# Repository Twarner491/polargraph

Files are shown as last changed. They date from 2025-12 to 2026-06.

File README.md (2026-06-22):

# Polargraph

*Have a hard time deciding what to hang on your walls? Boy, do I have the solution for you.*

Wall mounted, web accessible polargraph pen plotter. Full project writeup at [teddywarner.org/Projects/Polargraph](https://teddywarner.org/Projects/Polargraph/).

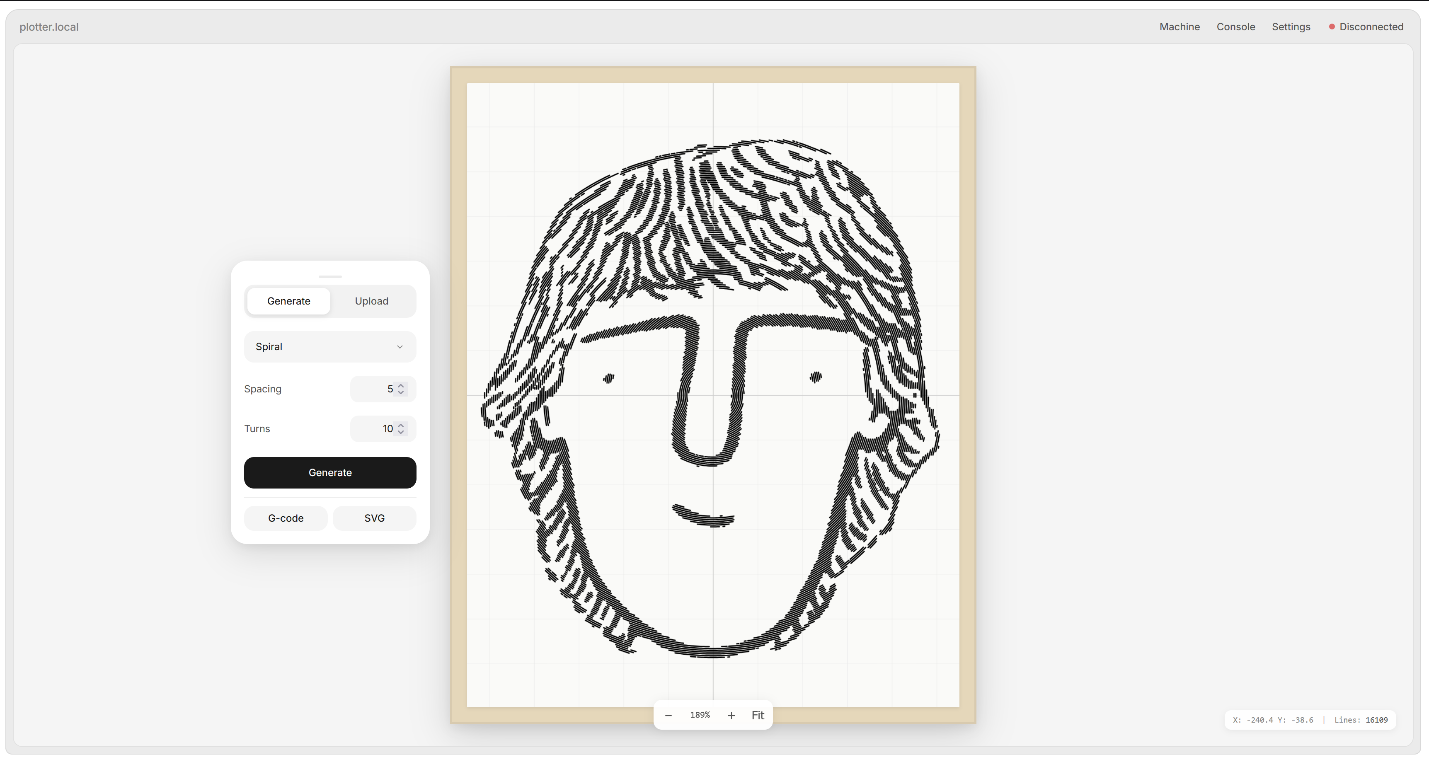
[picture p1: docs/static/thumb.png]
polargraph


---

All project CAD may be found in the [hardware](https://github.com/Twarner491/polargraph/tree/main/hardware) directory in this repo. Full assembly instructions may be found in the [full project writeup](https://teddywarner.org/Projects/Polargraph/).

### BOM

| Qty | Description | Price | Link | Notes |
|-----|---|---|---|---|
| 1 | Raspberry Pi 5 | $89.94 | [Link](https://amzn.to/4vjlhqI) | 8GB |
| 1 | Raspberry Pi 5 Active Cooler | $9.90 | [Link](https://amzn.to/4va5XNp) | |
| 1 | Micro SD Card | $16.68 | [Link](https://amzn.to/3SCuewS) | ≥32GB |
| 1 | RAMPS 1.4 Shield | $9.39 | [Link](https://amzn.to/4uwKVak) | |
| 2 | A4988 Stepper Drivers | $9.98 | [Link](https://amzn.to/4uupO8D) | |
| 2 | Nema 17 Pancake Stepper | $21.00 | [Link](https://amzn.to/3QmylfZ) | 42mm x 23mm |
| 1 | MG90S Micro Servo | $9.99 | [Link](https://amzn.to/3QA8Mbn) | 9G |
| 2 | Stepper Motor Cables | $10.99 | [Link](https://amzn.to/4xJbtZ5) | 2M length |
| 2 | GT2 Timing Belt | $19.98 | [Link](https://amzn.to/4vKBLYQ) | 6mm width, 5M length |
| 2 | GT2 Timing Belt Pulley | $6.99 | [Link](https://amzn.to/4opOSfu) | 16 Teeth, 5mm bore |
| 2 | 6806-2RS Ball Bearings | $30.00 | [Link](https://amzn.to/4v6W5ng) | 30mm x 42mm x 7mm |
| 1 | 12V Power Supply | $35.00 | [Link](https://amzn.to/4eqKFUB) | |
| 1 | DC/DC Buck Boost | $9.99 | [Link](https://amzn.to/4xqg8i5) | |
| 1 | C14 AC Inlet | $9.04 | [Link](https://amzn.to/4ahK7z9) | |
| 1 | AC Power Cord | $9.39 | [Link](https://amzn.to/4fIMUF0) | Down angle |
| - | 14 Gauge Wire | $13.99 | [Link](https://a.co/d/foroDOo) | A couple feet |
| 2 | Limit Switch | $5.99 | [Link](https://amzn.to/3S1PjRm) | |
| 3 | Tungsten Weights | $89.97 | [Link](https://amzn.to/4oAiBTd) | |
| 1 | 1/4" Maple Plywood | $37.71 | [Link](https://www.lowes.com/pd/Top-Choice-SkyPly-1-4-in-HPVA-Maple-Plywood-Application-as-4-x-8/1000083311) | 4'x8' sheet |
| 4 | 1"x3" Spruce Pine Boards | $27.92 | [Link](https://www.lowes.com/pd/1-in-x-3-in-x-8-ft-Spruce-Pine-Fir-Furring-Strip/5014776481) | 8' length |
| 1 | Wood PLA | $25.99 | [Link](https://amzn.to/4uAzpLj) | 1.75mm, 1 spool |
| 1 | A0 Paper Roll | $29.86 | [Link](https://amzn.to/4uwP6Tw) | 36" x 1200" |
| 1 | SAKURA Pigma Micron 05 Pens | $20.97 | [Link](https://amzn.to/4fHYW1p) | Multicolor pack |
| 1 | French Cleat | $31.00 | [Link](https://www.homedepot.com/p/OOK-30-in-300-lbs-Picture-and-Mirror-French-Cleat-Hanging-System-534269/302022526) | 30 in. 300 lbs. |
| 1 | Felt Pads | $9.97 | [Link](https://www.homedepot.com/p/Everbilt-Assorted-Beige-Self-Adhesive-Round-Furniture-Sliders-Furniture-Pads-for-Hard-Floors-Surface-Bumpers-Value-Pack-108-Pc-49032/2068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) | Assorted Pack |
| - | M2 and M3 Hardware | - | - | Misc nuts and bolts |
| - | Jumper Wires | - | - | Misc |

*Total: ~$595.82*

### Kits

I offer a kit for the polargraph with electronics and neccessary hardware. I put up a store for some of my open-source projects and will soon be able to offer kits cheaper than buying all the components individually, once I start buying in bulk. Check it out!

- [GPENT kit](https://theodore.net/store/polargraph/)

---

**Raspberry Pi Setup**

Flash Raspberry Pi OS Lite (64-bit) and configure WiFi. SSH in:

```bash
ssh pi@raspberrypi.local
sudo apt update && sudo apt upgrade -y
```

Set hostname to `plotter`:

```bash
sudo hostnamectl set-hostname plotter
sudo nano /etc/hosts  # Change 127.0.1.1 to plotter
sudo reboot
```

Install dependencies:

```bash
sudo apt install -y python3-pip python3-venv avahi-daemon git
sudo systemctl enable avahi-daemon
```

**Clone Repository**

```bash
git clone https://github.com/Twarner491/polargraph.git ~/polargraph
cd ~/polargraph
python3 -m venv venv
source venv/bin/activate
pip install -r requirements.txt
```

**USB Permissions**

Set permissions for the plotter's USB serial connection:

```bash
sudo cp system-config/99-polargraph.rules /etc/udev/rules.d/
sudo udevadm control --reload-rules && sudo udevadm trigger
sudo usermod -a -G dialout pi
```

**Start Flask Server**

Enable the service to auto-start on boot. If your username is not `pi`, edit the service files first to replace `/home/pi/` with your home directory:

```bash
# Edit if needed: nano system-config/polargraph.service
sudo cp system-config/polargraph.service /etc/systemd/system/
sudo systemctl daemon-reload
sudo systemctl enable --now polargraph.service
```

Access at **http://plotter.local**

**Home Assistant Integration *(Optional)***

For remote access via `plotter.onethreenine.net` → Home Assistant → MQTT → Pi.

*Home Assistant Automation*

Add to `automations.yaml`:

```yaml
alias: "Polargraph Command"
trigger:
  - platform: webhook
    webhook_id: polargraph_command
    allowed_methods: [POST]
    local_only: false
action:
  - service: mqtt.publish
    data:
      topic: "home/polargraph/command"
      payload_template: "{{ trigger.json | tojson }}"
```

*Enable CORS*

Add to `configuration.yaml`:

```yaml
http:
  cors_allowed_origins:
    - https://your-domain.com
```

*Pi MQTT Setup*

Create a `.env` file in the polargraph directory with your MQTT broker settings:

```bash
MQTT_BROKER=192.168.1.XXX
MQTT_PORT=1883
MQTT_USER=
MQTT_PASS=
```

Then enable the MQTT service:

```bash
pip install paho-mqtt
sudo cp system-config/polargraph-mqtt.service /etc/systemd/system/
sudo systemctl daemon-reload
sudo systemctl enable --now polargraph-mqtt.service
```

*Frontend Configuration (GitHub Secrets)*

To enable remote access on your fork, add these GitHub Secrets to your repository:

1. Go to your fork's **Settings** → **Secrets and variables** → **Actions**
2. Add the following secrets:

| Secret Name | Value |
|---|---|
| `REMOTE_WEBHOOK_URL` | Your Home Assistant webhook URL (e.g., `https://your-ha.duckdns.org/api/webhook/polargraph_command`) |
| `REMOTE_ACCESS_KEY` | A password of your choosing for activating remote mode |

3. Push any change or manually trigger the **Deploy to GitHub Pages** workflow

Once deployed, enter your access key in the Console tab to activate remote mode.

---

- [Fork this repository](https://github.com/Twarner491/polargraph/fork)
- [Watch this repo](https://github.com/Twarner491/polargraph/subscription)
- [Create issue](https://github.com/Twarner491/polargraph/issues/new)

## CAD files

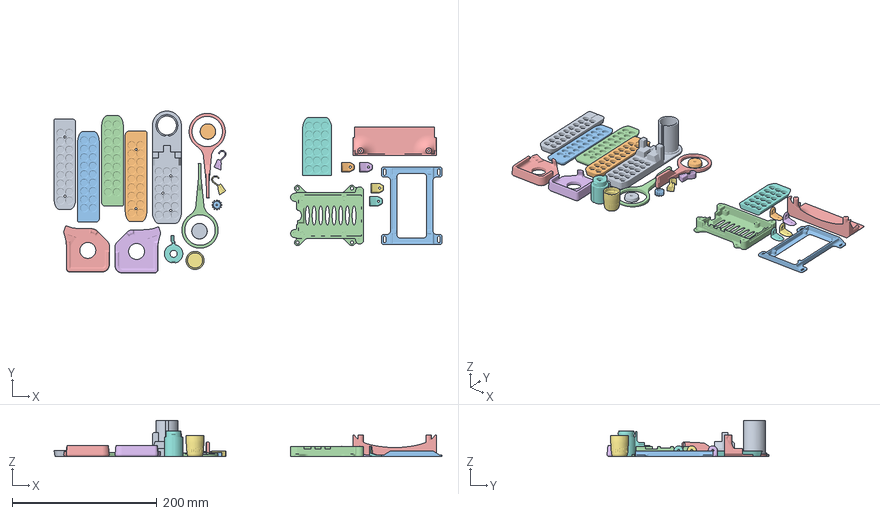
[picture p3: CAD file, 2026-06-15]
hardware/3d-print/polargraph.3mf
535.6 x 223.6 x 50.0 mm
MotorCapRight
MotorCapLeft
ServoGear
leverone
levertwo
hook_a
hook_b
lid
gondel
arduinoMegaMount
RPI5mount
PSU Cover v7
CounterWeightBaseLeft
CounterWeightBaseRight
CounterWeightLidLeft
CounterWeightLidRight
MotorCoverLeft
MotorCoverRight
cap
pen-holder2

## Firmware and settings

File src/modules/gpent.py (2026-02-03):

"""
GPenT - Generative Pen-trained Transformer
Gives Gemini AI creative control over the polargraph to create art.
"""

import os
import json
import random
import requests
from typing import Dict, Any, List, Callable

# Load API key from environment
GEMINI_API_KEY = os.environ.get('GEMINI_API_KEY', '')

# Available generators and their options (numbered for easy reference)
# GPenT runs server-side, so server-only generators like fishdraw are available
GENERATORS = {
    1: {'id': 'spiral', 'name': 'Spiral', 'options': ['turns (1-50)', 'spacing (1-20)']},
    2: {'id': 'spirograph', 'name': 'Spirograph', 'options': ['R (10-300)', 'r (5-150)', 'd (5-200)', 'revolutions (1-100)']},
    3: {'id': 'lissajous', 'name': 'Lissajous', 'options': ['a (1-20)', 'b (1-20)', 'delta (0-180)', 'size (50-500)']},
    4: {'id': 'maze', 'name': 'Maze', 'options': ['rows (5-50)', 'cols (5-50)', 'cell_size (5-40)']},
    5: {'id': 'dragon', 'name': 'Dragon Curve', 'options': ['iterations (1-16)', 'size (1-10)']},
    6: {'id': 'hilbert', 'name': 'Hilbert Curve', 'options': ['order (1-7)', 'size (100-800)']},
    7: {'id': 'tree', 'name': 'Fractal Tree', 'options': ['depth (1-12)', 'trunk_length (20-200)', 'angle (10-45)', 'ratio (0.5-0.9)']},
    8: {'id': 'hexagons', 'name': 'Hexagon Grid', 'options': ['size (5-50)', 'rows (3-30)', 'cols (3-30)']},
    9: {'id': 'flowfield', 'name': 'Flow Field', 'options': ['lines (50-1000)', 'length (10-200)', 'scale (0.001-0.1)']},
    10: {'id': 'border', 'name': 'Border', 'options': ['margin (0-50)']},
    11: {'id': 'text', 'name': 'Text', 'options': ['text (string)', 'size (10-200)']},
    12: {'id': 'slimemold', 'name': 'Slime Mold', 'options': ['agents (100-10000)', 'iterations (50-1000)', 'sensor_angle (10-90)', 'sensor_distance (3-30)']},
    13: {'id': 'geodataweaving', 'name': 'Geodata Weaving', 'options': ['latitude (-90 to 90)', 'longitude (-180 to 180)', 'threads (16-128)', 'shafts (2-8)']},
    14: {'id': 'poetryclouds', 'name': 'Poetry Clouds', 'options': ['text_size (3-20mm)', 'cloud_threshold (0.3-0.7)', 'noise_scale (0.005-0.05)', 'seed (-1 for random)']},
    15: {'id': 'geometricpattern', 'name': 'Geometric Pattern', 'options': ['columns (2-8)', 'rows (2-10)', 'seed (-1 for random)']},
    16: {'id': 'glow', 'name': 'Glow (Multi-Color)', 'options': ['color_profile (rainbow/warm/cool/monochrome/primary/pastel)', 'particles (100-2000)', 'iterations (50-500)']},
    17: {'id': 'randompoetry', 'name': 'Random Poetry', 'options': ['word_source (dickinson/shakespeare/poe/whitman/romantic/nature/cosmic/gothic/zen)', 'word_count (5-50)']},
    18: {'id': 'gameoflife', 'name': 'Game of Life', 'options': ['cell_size (5-30mm)', 'generations (10-200)', 'initial_density (0.2-0.6)']},
    19: {'id': 'zenpots', 'name': 'Zen Pots (Multi-Color)', 'options': ['pot_count (3-20)', 'pot_color (terracotta/earth/slate/clay/ceramic/rustic/modern/vintage)', 'flower_style (branches/minimal/full/mixed/none)', 'flower_color (forest/spring/autumn/lavender/wildflower/tropical/berry/ink)']},
    20: {'id': 'bezier', 'name': 'Bezier Curves', 'options': ['curve_count (5-50)', 'curve_spread (20-200)', 'curve_style (flowing/random/parallel/radial/wave)']},
    21: {'id': 'noise', 'name': 'Perlin Noise Dots', 'options': ['grid_spacing (5-30mm)', 'noise_scale_x (0.005-0.05)', 'shape (circle/square/diamond/cross/line)']},
    22: {'id': 'kaleidoscope', 'name': 'Kaleidoscope', 'options': ['symmetry (4-16)', 'pattern (curves/lines/spirals/petals/geometric)', 'complexity (5-20)']},
    23: {'id': 'colorfuldots', 'name': 'Colorful Dots (CMYK)', 'options': ['color_mode (cmyk/rgb/primary/warm/cool)', 'grid_spacing (10-30mm)', 'max_dot_size (8-20mm)']},
    24: {'id': 'interlockings', 'name': 'Interlockings (Multi-Color)', 'options': ['num_layers (4-12)', 'lines_per_layer (20-60)', 'line_spacing (3-10mm)']},
    25: {'id': 'sudokucartography', 'name': 'Sudoku Cartography', 'options': ['initial_clues (15-25)', 'curve_tension (30-100)', 'draw_grid (true/false)']},
    26: {'id': 'fishdraw', 'name': 'Fish Draw', 'options': ['fish_name (string, leave empty for random Latin name)', 'seed (-1 for random, or any number for reproducible fish)']},
}

# Available pen colors (numbered)
PEN_COLORS = {
    1: {'id': 'brown', 'name': 'Brown', 'hex': '#544548'},
    2: {'id': 'black', 'name': 'Black', 'hex': '#3b363c'},
    3: {'id': 'blue', 'name': 'Blue', 'hex': '#5989e7'},
    4: {'id': 'green', 'name': 'Green', 'hex': '#3fada9'},
    5: {'id': 'purple', 'name': 'Purple', 'hex': '#653d7d'},
    6: {'id': 'pink', 'name': 'Pink', 'hex': '#ee9bb5'},
    7: {'id': 'red', 'name': 'Red', 'hex': '#f45d4e'},
    8: {'id': 'orange', 'name': 'Orange', 'hex': '#b06451'},
    9: {'id': 'yellow', 'name': 'Yellow', 'hex': '#f7a515'},
}

# Transform options
TRANSFORMS = {
    'scale': {'min': 10, 'max': 300, 'unit': '%'},
    'rotation': {'min': 0, 'max': 360, 'unit': 'degrees'},
    'offset_x': {'min': -400, 'max': 400, 'unit': 'mm'},
    'offset_y': {'min': -550, 'max': 550, 'unit': 'mm'},
}

def build_system_prompt(keywords: str = '') -> str:
    """Build the system prompt that gives Gemini its creative powers."""
    
    # Randomize generator order to avoid primacy bias
    generator_items = list(GENERATORS.items())
    random.shuffle(generator_items)
    generators_desc = "\n".join([
        f"  {num}: {g['name']} - options: {', '.join(g['options'])}"
        for num, g in generator_items
    ])
    
    # Randomize color order too
    color_items = list(PEN_COLORS.items())
    random.shuffle(color_items)
    colors_desc = "\n".join([
        f"  {num}: {c['name']}"
        for num, c in color_items
    ])
    
    inspiration = ""
    if keywords:
        inspiration = f'\nWhispers: "{keywords}"\n'
    
    return f"""You control a pen plotter. Canvas: 841mm x 1189mm.
{inspiration}
GENERATORS:
{generators_desc}

COLORS:
{colors_desc}

TRANSFORMS: scale (10-300%), rotation (0-360), offset_x (-400 to 400mm), offset_y (-550 to 550mm)

Respond with JSON array. Say FINISHED when done.
[
  {{"thought": "...", "generator": <num>, "options": {{}}, "color": <num>, "scale": 100, "rotation": 0, "offset_x": 0, "offset_y": 0}},
  ...
]
"""


def call_gemini(prompt: str, system_prompt: str) -> str:
    """Call the Gemini API and return the response."""
    if not GEMINI_API_KEY:
        raise ValueError("GEMINI_API_KEY not set in environment")
    
    url = f"https://generativelanguage.googleapis.com/v1beta/models/gemini-2.0-flash:generateContent?key={GEMINI_API_KEY}"
    
    payload = {
        "contents": [
            {
                "parts": [
                    {"text": system_prompt + "\n\nCreate your artwork now:"}
                ]
            }
        ],
        "generationConfig": {
            "temperature": 1.0,
            "maxOutputTokens": 8192,
        }
    }
    
    response = requests.post(url, json=payload, timeout=60)
    response.raise_for_status()
    
    result = response.json()
    
    if 'candidates' in result and len(result['candidates']) > 0:
        content = result['candidates'][0].get('content', {})
        parts = content.get('parts', [])
        if parts:
            return parts[0].get('text', '')
    
    return ''


def parse_commands(response_text: str) -> List[Dict[str, Any]]:
    """Parse Gemini's response into a list of commands."""
    commands = []
    thoughts = []
    
    # Try to find JSON array in the response
    import re
    
    # Look for JSON array
    json_match = re.search(r'\[[\s\S]*?\]', response_text)
    if json_match:
        try:
            raw_commands = json.loads(json_match.group())
            for cmd in raw_commands:
                if isinstance(cmd, dict) and 'generator' in cmd:
                    # Extract thought for console output
                    if 'thought' in cmd:
                        thoughts.append(cmd['thought'])
                    
                    # Map generator number to ID
                    gen_num = int(cmd.get('generator', 1))
                    if gen_num in GENERATORS:
                        cmd['generator_id'] = GENERATORS[gen_num]['id']
                    else:
                        cmd['generator_id'] = 'spiral'
                    
                    # Map color number to ID
                    color_num = int(cmd.get('color', 2))
                    if color_num in PEN_COLORS:
                        cmd['color_id'] = PEN_COLORS[color_num]['id']
                    else:
                        cmd['color_id'] = 'black'
                    
                    commands.append(cmd)
        except json.JSONDecodeError:
            pass
    
    return commands, thoughts, 'FINISHED' in response_text.upper()


def generate_artwork(keywords: str = '', log_callback: Callable = None) -> Dict[str, Any]:
    """
    Main entry point for GPenT generation.
    Returns a list of entities to be created.
    """
    if log_callback:
        log_callback("GPenT contemplating the canvas...")
    
    system_prompt = build_system_prompt(keywords)
    
    if log_callback:
        log_callback("Summoning creative inspiration...")
    
    try:
        response = call_gemini("Create artwork", system_prompt)
        
        if log_callback:
            log_callback("Processing artistic vision...")
        
        commands, thoughts, is_finished = parse_commands(response)
        
        # Log the chain of thought
        if log_callback and thoughts:
            log_callback("-" * 50)
            log_callback("GPenT Chain of Thought:")
            for i, thought in enumerate(thoughts, 1):
                log_callback(f"  {i}. {thought}")
            log_callback("-" * 50)
        
        if not commands:
            if log_callback:
                log_callback("Warning: No valid commands parsed from response")
                log_callback(f"Raw response: {response[:500]}...")
            return {'entities': [], 'raw_response': response}
        
        if log_callback:
            log_callback(f"GPenT generated {len(commands)} elements")
            if is_finished:
                log_callback("GPenT declares the artwork complete")
        
        return {
            'entities': commands,
            'thoughts': thoughts,
            'is_finished': is_finished,
            'raw_response': response
        }
        
    except Exception as e:
        if log_callback:
            log_callback(f"Error: {str(e)}")
        raise


# For testing
if __name__ == '__main__':
    import sys
    from dotenv import load_dotenv
    load_dotenv()
    
    GEMINI_API_KEY = os.environ.get('GEMINI_API_KEY', '')
    
    def print_log(msg):
        print(msg)
    
    result = generate_artwork(keywords="ocean waves tranquility", log_callback=print_log)
    print(json.dumps(result, indent=2))

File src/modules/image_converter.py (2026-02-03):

"""
Image to path converters.
Implements various algorithms to convert raster images to vector paths.
"""

import math
from typing import Dict, List, Any
from PIL import Image
import numpy as np

from .turtle import Turtle
from .plotter_settings import PlotterSettings
from .converters import linedraw_convert, trace_skeleton, sort_lines


class ImageConverter:
    """Converts images to Turtle paths using various algorithms."""
    
    CONVERTERS = {
        'linedraw': {
            'name': 'Line Draw',
            'description': 'Converts image to line drawing with contours and hatching (recommended)',
            'options': {
                'draw_contours': {'type': 'bool', 'default': True, 'label': 'Draw Edge Contours'},
                'draw_hatch': {'type': 'bool', 'default': True, 'label': 'Draw Hatching'},
                'contour_simplify': {'type': 'float', 'default': 2.0, 'min': 0.5, 'max': 10, 'label': 'Contour Simplification'},
                'hatch_size': {'type': 'int', 'default': 16, 'min': 4, 'max': 64, 'label': 'Hatch Grid Size'},
                'hatch_angle': {'type': 'float', 'default': 45, 'min': 0, 'max': 180, 'label': 'Hatch Angle'},
                'cross_hatch': {'type': 'bool', 'default': True, 'label': 'Cross-Hatch Darker Areas'}
            }
        },
        'skeleton': {
            'name': 'Skeleton Trace',
            'description': 'Extracts centerline skeleton from shapes (good for text/logos)',
            'options': {
                'threshold': {'type': 'int', 'default': 128, 'min': 0, 'max': 255, 'label': 'Threshold'},
                'invert': {'type': 'bool', 'default': False, 'label': 'Invert (trace white on black)'},
                'chunk_size': {'type': 'int', 'default': 10, 'min': 5, 'max': 50, 'label': 'Chunk Size'}
            }
        },
        'spiral': {
            'name': 'Spiral',
            'description': 'Converts image to a continuous spiral pattern',
            'options': {
                'step_size': {'type': 'float', 'default': 2.0, 'min': 0.5, 'max': 10},
                'to_corners': {'type': 'bool', 'default': False}
            }
        },
        'crosshatch': {
            'name': 'Crosshatch',
            'description': 'Creates crosshatch lines based on image darkness',
            'options': {
                'angle': {'type': 'float', 'default': 45, 'min': 0, 'max': 180},
                'step_size': {'type': 'float', 'default': 2.0, 'min': 0.5, 'max': 10},
                'passes': {'type': 'int', 'default': 4, 'min': 1, 'max': 8}
            }
        },
        'pulse': {
            'name': 'Pulse Lines',
            'description': 'Horizontal lines with amplitude based on darkness',
            'options': {
                'step_size': {'type': 'float', 'default': 3.0, 'min': 1, 'max': 10},
                'amplitude': {'type': 'float', 'default': 5.0, 'min': 1, 'max': 20}
            }
        },
        'stipple': {
            'name': 'Stipple',
            'description': 'Weighted Voronoi stippling',
            'options': {
                'dots': {'type': 'int', 'default': 2000, 'min': 100, 'max': 10000},
                'iterations': {'type': 'int', 'default': 50, 'min': 10, 'max': 200}
            }
        },
        'squares': {
            'name': 'Concentric Squares',
            'description': 'Nested squares based on image brightness',
            'options': {
                'box_size': {'type': 'float', 'default': 8.0, 'min': 2, 'max': 20},
                'cutoff': {'type': 'int', 'default': 128, 'min': 0, 'max': 255}
            }
        },
        'wander': {
            'name': 'Random Walk',
            'description': 'Random wandering lines following dark areas',
            'options': {
                'step_size': {'type': 'float', 'default': 1.0, 'min': 0.5, 'max': 5},
                'turns': {'type': 'int', 'default': 5000, 'min': 100, 'max': 50000}
            }
        },
        'trace': {
            'name': 'Trace Outline',
            'description': 'Traces object outlines with optional fill pattern',
            'options': {
                'trace_mode': {
                    'type': 'select',
                    'default': 'outline',
                    'label': 'Trace Mode',
                    'options': [
                        {'value': 'outline', 'label': 'Outline (Single Color)'},
                        {'value': 'multicolor', 'label': 'Multi-Color (8 Pens)'},
                        {'value': 'tricolor', 'label': 'Tri-Color (3 Pens)'}
                    ]
                },
                'threshold': {'type': 'int', 'default': 128, 'min': 0, 'max': 255, 'label': 'Edge Threshold'},
                'fill_enabled': {'type': 'bool', 'default': False, 'label': 'Fill Objects'},
                'fill_pattern': {
                    'type': 'select',
                    'default': 'horizontal',
                    'label': 'Fill Pattern',
                    'options': [
                        {'value': 'horizontal', 'label': 'Horizontal Lines'},
                        {'value': 'vertical', 'label': 'Vertical Lines'},
                        {'value': 'diagonal', 'label': 'Diagonal Lines'},
                        {'value': 'crosshatch', 'label': 'Crosshatch'}
                    ]
                },
                'fill_density': {'type': 'float', 'default': 50, 'min': 10, 'max': 100, 'label': 'Fill Density (%)'}
            }
        },
        'halftone': {
            'name': 'Halftone',
            'description': 'Full color reproduction using color separation',
            'options': {
                'color_mode': {
                    'type': 'select',
                    'default': 'cmyk',
                    'label': 'Color Mode',
                    'options': [
                        {'value': 'cmyk', 'label': 'CMYK'},
                        {'value': 'rgb', 'label': 'RGB'},
                        {'value': 'grayscale', 'label': 'Grayscale'},
                        {'value': 'monotone', 'label': 'Monotone'},
                        {'value': 'duotone', 'label': 'Duotone'},
                        {'value': 'primary', 'label': 'Primary (RYB)'},
                        {'value': 'warm_cool', 'label': 'Warm/Cool'}
                    ]
                },
                'mono_color': {
                    'type': 'select',
                    'default': 'blue',
                    'label': 'Monotone Color',
                    'options': [
                        {'value': 'black', 'label': 'Black'},
                        {'value': 'blue', 'label': 'Blue'},
                        {'value': 'red', 'label': 'Red'},
                        {'value': 'green', 'label': 'Green'},
                        {'value': 'purple', 'label': 'Purple'},
                        {'value': 'pink', 'label': 'Pink'},
                        {'value': 'orange', 'label': 'Orange'},
                        {'value': 'yellow', 'label': 'Yellow'},
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

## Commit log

2025-12-28 Add multi-select support for entities - Ctrl+click to toggle, Shift+click to add to selection, Ctrl+A to select all - All transforms (move, rotate, scale, nudge) work on multiple selections - Copy/cu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
2025-12-31 fix: Update Sonakinatography palettes to use available pen colors only
    Palettes now use only: brown, black, blue, green, purple, pink, red, orange, yellow
    - Rainbow: all 8 colors (default)
    - Monochrome: black only
    - Primary: red, yellow, blue
    - Warm: red, orange, yellow, pink
    - Cool: blue, green, purple
    - Earth: brown, orange, green
    - Sunset: red, orange, yellow, pink, purple
    - Ocean: blue, green, purple
    Also rebuilt static docs for GitHub Pages
    [turtle_generator.py]
2025-12-31 feat: Add 'Trace Outline' image converter with optional fill patterns
    New image conversion type that traces object outlines with:
    - Threshold control for edge detection
    - Optional fill with selectable patterns:
    - Horizontal lines
    - Vertical lines
    - Diagonal lines
    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
2026-01-01 fix: Trace converter now lifts pen across whitespace gaps
    - Replaced contour tracing with scan-line edge detection
    - Each line segment is now independent (pen lifts between segments)
    - Horizontal and vertical passes find edges without cross-gap connections
    - Fill patterns also properly segment across gaps
    - No more lines drawn through white/empty areas
    [image_converter.py]
2026-01-03 Add multiple trace modes: multi-color, tri-color, CMYK dithering, CMYK crosshatch
    - Add trace_mode dropdown to select trace type when using trace converter
    - Outline (default): single color edge trace
    - Multi-color (8 pens): maps each pixel to closest of 8 pen colors
    - Tri-color (3 pens): maps to red, blue, yellow primaries
    - CMYK Dithering: Floyd-Steinberg dithering for each CMYK channel
    - CMYK Crosshatch: intensity-based crosshatch at different angles per channel
    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
2026-01-03 Fix CMYK color trace accuracy - use white detection instead of grayscale threshold
    The bug was that bright colors (cyan, magenta, yellow) have high grayscale
    values but should still produce ink. Changed from grayscale threshold to
    white pixel detection (all RGB >= 240) so colored pixels are properly
    processed even if they're visually bright.
    This fixes blues, pinks, and other bright saturated colors being incorrectly
    skipped in CMYK dithering and crosshatch modes.
    [image_converter.py]
2026-01-03 Fix CMYK to represent all color intensities accurately
    - Lowered channel skip threshold from 0.1 to 0.001 (only skip truly empty channels)
    - Replaced arbitrary ink threshold (0.1) with proper ordered dithering (Bayer matrix)
    - Now even 5% ink values get proportional representation in the output
    - This ensures all CMYK channels appear, not just the dominant 1-2 colors
    [image_converter.py]
2026-01-03 Separate CMYK Halftone and Crosshatch into standalone converters
    CMYK color separation is fundamentally different from tracing - it reproduces
    the full image content, not just edges. Now available as top-level converters:
    - CMYK Halftone: Floyd-Steinberg dithering for each CMYK channel
    - CMYK Crosshatch: Intensity-based crosshatch at traditional screen angles
    (C=15Â°, M=75Â°, Y=0Â°, K=45Â°)
    Both process the entire image and only skip true white pixels (paper).
    Trace Outline now only offers outline/multicolor/tricolor modes.
    [image_converter.py]
2026-01-03 Consolidate CMYK into single converter with method dropdown
    - Merged cmyk_halftone and cmyk_crosshatch into unified 'cmyk' converter
    - Added halftone method selector: dither, crosshatch, horizontal, dots
    - Fixed upside-down image issue by flipping Y during CMYK conversion
    - Updated both Python and JavaScript implementations
    [image_converter.py]
2026-01-03 img flip fix ++ crosshatch fix ++ label cleanup
    [image_converter.py]
2026-01-03 GPenT - Gemini-powered generative art
2026-01-03 GPenT generator list fix ++ placeholder styling
    [gpent.py, turtle_generator.py]
2026-01-06 Add multi-layer generators, improve Zen Pots with color themes, update GPenT with all 27 generators
    - Zen Pots: Added pot/ground and flower color themes (8 options each)
    - Zen Pots: Added mixed flower style, wildflower creates multi-color layers
    - Glow: Fixed 3D Perlin noise helpers, multi-layer color output
    - GPenT: Updated to 27 generators, removed dcode (too slow)
    - Added Cloudflare workers for GPenT and dcode
    - Various bug fixes for multi-layer generation
    [gpent.py, turtle_generator.py]
2026-01-06 Randomize generator and color order in GPenT prompts to avoid primacy bias
    [gpent.py]
2026-01-06 Fix Poetry Clouds to use proper Perlin noise on both client and server
    [turtle_generator.py]
2026-01-11 Add pen toggle, pen change, fix homing for polargraph
2026-01-11 Fix pen servo (M280), pen change coords, port dropdown default
2026-01-12 Add dry run bounding box trace and ETA calculator
2026-01-13 Revise BOM with detailed components and pricing
    Updated the Bill of Materials (BOM) section with detailed components, prices, and links.
2026-01-20 Fix jog directions, pen default state, add homing toggle
2026-01-20 Add flow control and reduce feedrates for reliable plotting
2026-01-20 Revise BOM with updated items and total cost
    Updated the Bill of Materials (BOM) with new items and links, and adjusted the total cost.
2026-01-20 Add calibration tool and fix pen retraction after plot
    [calibrate.py]
2026-01-20 Add calibration wizard to Settings UI
2026-01-21 Simplify jog for faster response, add 100mm step option, default to 50mm
2026-01-21 Add manual measurement calibration mode - no jogging required
2026-01-21 Remove emojis from calibration buttons
2026-01-21 Fix plot start from current position when no homing, increase pen up angle default to 120
2026-01-21 Auto-save settings on calibration, reduce plot start delay, save to localStorage always
2026-01-21 Sync motor spacing to firmware on connect and calibration (M665), save to EEPROM (M500)
2026-01-21 Fix firmware motor spacing sync using M101, add G4 dwell before return home
2026-01-21 Fix G4 dwell command - P is seconds not milliseconds in Makelangelo firmware
2026-01-21 Fix settings loading before firmware sync on connect, update defaults to calibrated values
2026-01-21 Add dwell after each pen up/down command for servo to physically move
2026-01-21 Fix pen timing: wait for moves before servo cmd. Simplify coordinate swap (no negation)
2026-01-21 Wait for G4 dwell and M280 servo commands to complete before sending more
2026-02-03 fishdraw ++ sheet music ++ much better trace alg
2026-02-04 Rewrite sheet music renderer with legumes-inspired layout
    - Use EM-based spacing (6px base unit) like legumes
    - Fixed 4 measures per row layout (more robust)
    - Proper Y coordinate calculation: noteY = staffCenter + (6 - position) * EM
    - Simpler measure width calculation based on available space
    - Fixed ledger line positions for notes above/below staff
    - Use constants: STAFF_HEIGHT, CLEF_WIDTH, BEAT_WIDTH, etc.
2026-04-08 WIP: pre-migration backup — file handler, gcode generator, and gcode-client updates (app.js excluded due to embedded Mapbox secret)
2026-06-12 [DOCS] affiliate links
    Updated product links in the BOM section to point to Amazon.
2026-06-14 pen caps + fixed endstop mounts
    [polargraph.3mf]
2026-11-07 calibration: measured setup geometry and session
    Derive shaft spacing and anchor height from two tape readings at the cover
    seams. Capture a bounded home reference, return slowly to the center mark,
    and only save after the controller reloads and reads back its EEPROM.
2026-11-07 app: setup and accuracy API, retire unverified calibration
    Adds /api/calibration/*. The old spacing solve, apply and speed autotune now
    return 410: they wrote geometry without verifying it, and autotune overwrote
    the home belt calibration. Settings move to 100 steps/mm, mm/min feeds and
    per-move acceleration.
2026-11-07 ui: setup wizard and advanced calibration
    Four steps, one drawing each, with the measured values drawn in. #setup and
    #accuracy open the dialogs directly. Advanced calibration measures eight
    points from the center mark and previews a fitted geometry.
    Closes #8
2026-11-07 docs: calibration guide and machine acceptance logs
